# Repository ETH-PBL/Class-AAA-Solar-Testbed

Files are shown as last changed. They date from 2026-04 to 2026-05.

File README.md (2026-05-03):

<p align="center">
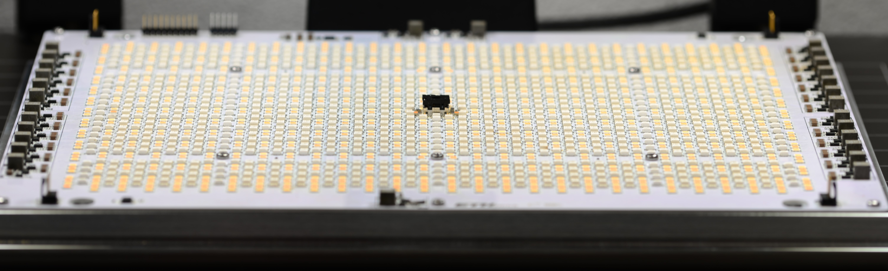
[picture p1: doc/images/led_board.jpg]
led board
  
</p>

# Open Source AAA-Grade Solar Testbed
This repository contains the hardware design files for the AAA-grade solar testbed.
It can accurately reproduce both indoor and outdoor lighting conditions, from ultra-low, narrow-band artificial light to full-spectrum sunlight. This enables a stable and repeatable evaluation environment with spectrally configurable illumination, making it ideal for evaluating ultra-low-power energy harvesting systems.

An in-depth analysis of the hardware can be found here: [arXiv.2604.24950 (preprint)](https://arxiv.org/abs/2604.24950)

> <div align="justify"> Energy harvesting promises maintenance-free operation of wireless sensor nodes but introduces strong dependencies on stochastic and deployment-specific environmental conditions. In particular, solar-powered systems are highly sensitive to variations in irradiance and spectral composition, which complicates system-level design, parameter tuning, and reliable verification. This work presents a solar testbed in which active control via Hardware-in-the-Loop (HIL) enables stable and repeatable illumination conditions for evaluating ultra-low-power energy harvesting systems. The proposed LED-based solar testbed provides spectrally configurable illumination over a wide dynamic range, from 5.7 mW/m2 to 908 kW/m2. It achieves Class AAA performance according to IEC 60904-9, with a spectral match below 1.3% and a spatial non-uniformity below 1.28% over a 16.5 cm x 16.5 cm test area. The long-term irradiance instability remains below 0.6%. Closed-loop control using integrated illuminance and spectral sensors ensures high temporal stability, while a temperature-controlled DUT stage supports long-term experiments. Experimental results demonstrate high repeatability and suitability for systematic laboratory characterization of solar energy harvesting systems.</div>

## Key Features
- **Class AAA Solar Simulator** compliant with [IEC 60904-9](https://webstore.iec.ch/publication/28973)
- **Spectrally tunable LED light source** composed of eight different LED types allows for emulation of natural and artificial light sources
- **Wide irradiance range** from **5.7 mW/m² to 908 W/m² (~1 lx to 110 klx)**
- **Large uniform illumination area** of 16.5 cm × 16.5 cm
- **Temperature-controlled platform** to keep the device under test (DUT) at a constant temperature

## Ussage
The solar testbed is designed to operate as part of a laboratory measurement setup in which a host computer, the testbed itself, and external measurement instruments interact closely. A computer connects to the testbed via USB and acts as the central orchestration unit. It configures and controls the illumination conditions, such as intensity and spectral composition, and coordinates the timing and execution of experiments.

Within this setup, the solar testbed provides a controlled and reproducible illumination environment but does not perform electrical measurements itself. The light board generates the desired illumination, while the internal control board distributes commands and manages the subsystems. The device under test (solar cell), is mounted on the carrier board, which ensures precise positioning and reproducible alignment within the illumination field.

Electrical access to the DUT is provided via two banana jack connectors. This allows the DUT to be interfaced directly with external measurement equipment, such as source measurement units, oscilloscopes, or data acquisition systems. Alternatively, an energy harvesting circuit can be connected between the solar cell and the measurement equipment, enabling system-level characterization under controlled lighting conditions.

The figure below show illustrates its functionality in a possible measurement setup.

<p align="center">
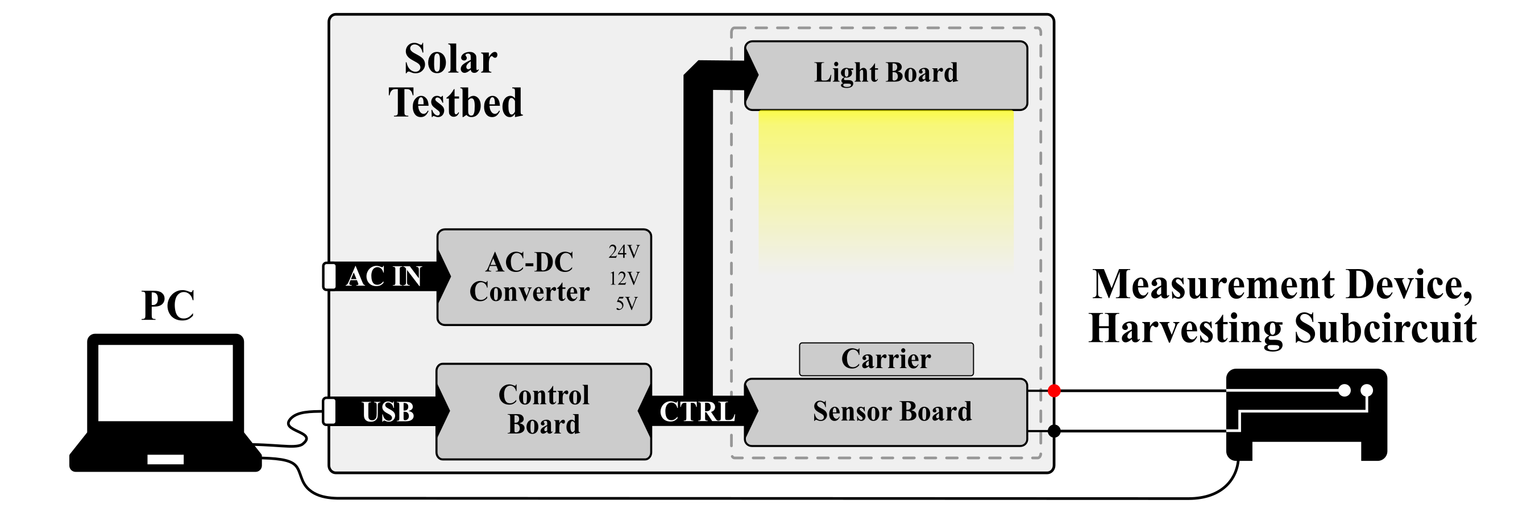
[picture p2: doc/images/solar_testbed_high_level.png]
solar tesbed high-level
  
</p>

# System Overview
The solar testbed is composed of both custom-designed and commercially available electronic and mechanical components. Its mechanical structure is based on custom heat sinks combined with standard 3030 aluminum profiles, enabling precise alignment and integration of all subsystems. While power stages and AC-to-DC converters are off-the-shelf components, the light source, sensing system, and control electronics are fully custom-designed.

The figure below provides a high-level overview of the main components.

<p align="center">
  led board
</p>

## Electrical
The testbed consists of four main subsystems implemented on separate PCBs:
- **Light Board:** A custom illumination board integrates 2964 LEDs of eight different types, mounted on a dedicated heat sink, enabling precise control of spectrum and intensity. It combines broadband visible LEDs, RGB LEDs for fine tuning, and infrared LEDs to emulate natural lighting conditions. The LEDs are driven by constant-current drivers with 16-bit dimming resolution, while integrated fan controllers ensure active cooling.

- **Sensor Board:** The sensor board monitors spectral distribution, illuminance, and temperature. It integrates an 18-channel spectrometer, two complementary ambient light sensors covering a wide illuminance range, and Peltier elements for temperature stabilization. Thermal control supports both heating and cooling, with additional fan-assisted stabilization.

- **Carrier Board:** The carrier board enables precise positioning and easy exchange of the device under test (DUT). It connects via an M.2 interface and provides external access through terminals. Integrated temperature sensing and controlled mounting ensure reproducible experimental conditions.

- **Control Board:** The control board coordinates all subsystems using an STM32 Cortex-M4 microcontroller. It manages illumination, temperature control, and overall system operation, and provides a USB Type-C interface for external communication. It further allows the addition of a single board comupter such as a Raspberry Pi to take control over high level control of the measurement  

All design files for the **custom designed PCBs** can be found [here](./hw/ecad/).  
Apart from the PCBs described above, the list of **commercial electrical components** used can be found [here](./hw/ecad/commercial_electrical_components.csv).

## Mechanical
The mechanical structur of the solar testbed consists of custom and commercial mechanical components.
Its mechanical structure is based on custom heat sinks combined with standard 3030 aluminum profiles.

- **Custom Parts:** 3D models and manufacturing drawings for the custom mechanical parts can be found [here](./hw/mcad/).

- **Commercial parts:** A list of commercially available mechanical components can be found here.

## Repository Structure
The repository has the following folders:  
- `doc` contains project documentation
- `hw` cntains all files of the solar testbed where in:
  - `ecad` all source files for the electronics (pcb design files, list of commerical components) are locaded
  - `mcad` all soruce files for mechanical componets (metal and plastic) including their 3d models and fabrication information are located

**Inportant:** This repository currently includes hardware only. Firmware, control software, and calibration tooling are not yet released. 

## Citation
If you use the solar testbed in an academic or industrial context, please cite the following publication:

```bibtex
@misc{schulthess_stb_2026,
    title           = {A Class AAA Solar Testbed for Reproducible Long-Term Characterization of Energy-Harvesting Systems}, 
    author          = {Lukas Schulthess and Andreas R\"atz and Michele Magno and Philipp Mayer},
    year            = {2026},
    eprint          = {2604.24950},
    archivePrefix   = {arXiv},
    doi             = {10.48550/arXiv.2604.24950},
    url             = {https://arxiv.org/abs/2604.24950}, 
}
```

## Contribution
The Solar Testbed has been designed at the [D-ITET Center-for Project-Based Learning](https://pbl.ee.ethz.ch/) and the [Integrated Systems Laboratory (IIS)](https://iis.ee.ethz.ch/) at ETH Zurch by:
 
[Lukas Schulthess](https://scholar.google.com/citations?user=nVuY91QAAAAJ&hl=en&oi=ao)  
[Philipp Mayer](https://scholar.google.com/citations?hl=en&user=1sCHClkAAAAJ)  
[Andreas Rätz](https://www.linkedin.com/in/andreas-r%C3%A4tz-2a439622b/)  

# License
All licenses used in this repository are licated in the `LICENSES` folder. 
Unless specified otherwise in the respective file headers, all code checked into this repository is made available under a permissive license.

- Hardware located under `hardware/` are lincense under the [Solderpad Hardware License v0.51](https://solderpad.org/licenses/SHL-0.51/) license.
- Markdown, JSON, text files, pictures, and PDFs are licensed under the [Creative Commons Attribution 4.0 International license](https://creativecommons.org/licenses/by/4.0/deed.en) (CC BY 4.0).

# Changelog
A detailed changelog is available in the [CHANGELOG.md](CHANGELOG.md) file, documenting major updates and design revisions.

## Disclaimer & Limitation of Liability
This project is a **research prototype** and is **not a commercial product**.  
It is provided for research, educational, and experimental purposes only. It is not certified for safety-critical or commercial use.

The system involves:
- high-intensity light sources  
- electrical power systems  
- thermal components (e.g., heating/cooling elements)  

Improper use, failures in self-assembly, or modification may result in:
ersonal injury  
- damage to equipment  
- unsafe operating conditions  

Users are solely responsible for ensuring safe design, assembly, and operation.

In no event and under no legal theory, whether in tort (including negligence), contract, or otherwise, unless required by applicable law (such as deliberate and grossly negligent acts) or agreed to in writing, shall any Contributor be liable to You for damages, including any direct, indirect, special, incidental, or consequential damages of any character arising as a result of this License or out of the use or inability to use the Work, including but not limited to:

- loss of goodwill  
- work stoppage  
- computer failure or malfunction  
- equipment damage  
- personal injury  
- or any other commercial or non-commercial damages or losses  

even if such contributor has been advised of the possibility of such damages.

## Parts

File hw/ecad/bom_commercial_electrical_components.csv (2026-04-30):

Component | Part Number / Model | Quantity
DC/DC Converter (54 W, 5 V out) | MEAN WELL DDR-60G-5 | 1
DC/DC Converter (60 W, 12 V out) | MEAN WELL DDR-60G-12 | 1
Power Supply Rail Mount 480W | Weidmuller 1469510000 | 1
Circuit Breaker | Weidmuller 2822220000 | 1
Peltier Module | Same Sky CP603315H | 4
Heat Sink Fan | NF-A14 PWM | 6
Door Sensor | Bernstein MAK-5236-BCD-6 | 1
Door Sensor Magnet | Bernstein TK-52-CD | 1
AC Power Entry Module | TE Connectivity 10CE1 M0 | 1
RGB Push Button | Metzler P19-TF-RGB | 1
HDMI Panel Mount | Adafruit 4129 | 1
Ethernet Panel Mount (RJ-45) | Adafruit 4130 | 1
USB-C Panel Mount | Adafruit 4261 | 1
Banana Jack 4mm (Red) | Cal Test CT4397-02-2 | 1
Banana Jack 4mm (Black) | Cal Test CT4397-02-0 | 1

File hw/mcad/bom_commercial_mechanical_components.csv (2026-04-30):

Name | Order Number | Supplier | Quantity
30x30 Aluminum Profile, B-Type Slot 8 (350 mm) | 30x30 B-Typ Nut 8 | Motedis | 10
30x30 Aluminum Profile, B-Type Slot 8 (485 mm) | 30x30 B-Typ Nut 8 | Motedis | 4
30x30 Aluminum Profile, B-Type Slot 8 (400 mm) | 30x30 B-Typ Nut 8 | Motedis | 2
Cube Connector 30, B-Type Slot 8 (2D) with cap | 65 | Motedis | 4
Cube Connector 30, B-Type Slot 8 (3D) with cap | 65 | Motedis | 4
Angle Bracket 30, B-Type Slot 8 | S8BBR30 | Motedis | 8
Cover and Edge Profile, Black, B-Type Slot 8 | 8PSIL08BR | Motedis | 10
Handle PA6 | 9343 | Motedis | 1
Hammer Nut, B-Type Slot 8 (M4) | S8BHASNM4 | Motedis | 4
Hammer Nut, B-Type Slot 8 (M5) | S8BHASNM5 | Motedis | 20
Hammer Nut, B-Type Slot 8 (M6) | S8BHASNM6 | Motedis | 20
Countersunk screw DIN 7991 M8x25 | 1120 | Motedis | 20
Countersunk screw DIN 7991 M4x12 | 1120 | Motedis | 20
Screw DIN 912 M6x12 | 1121 | Motedis
Wheel 75mm | 06.07.05 | Motedis | 4
Zinc Die-Cast Hinge | GN 127-ZD-52-40-B-SW | Hanser | 3
Draw latches | GN 936-72-SCL-SW | Hanser | 1
Metal Housing for power subsystem | ALN314016B | Fibox | 1

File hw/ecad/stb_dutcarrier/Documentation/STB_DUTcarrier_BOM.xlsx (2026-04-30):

Quantity | Designator | Comment | Value | Tolerance | Power | Footprint | Manufacturer | Manufacturer Part Number
1 | C1 | 100nF | 100nF |  |  | CAPC1050X55X23LL05T13 | Samsung Electro-Mechanics | CL05B104KO5NNNC
1 | R2 | 100k | 100 kOhm | 1% |  | RESC1005X40X25LL05T10 | Yageo / Phycomp | RC0402FR-07100KL
1 | U1 | TMP116NAIDRVR |  |  |  | FP-DRV0006B-MFG | Texas Instruments | TMP116NAIDRVR

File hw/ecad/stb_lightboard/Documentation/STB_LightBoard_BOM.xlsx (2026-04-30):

Quantity | Designator | Comment | Value | Tolerance | Power | Footprint | Manufacturer | Manufacturer Part Number
1 | J1 | 1050281001 |  |  |  | FP-1050281001-MFG | Molex | 1050281001
1 | L2 | DFE201612E-2R2M=P2 | 2.2uH | ±20% |  | INDC2016X10L | Murata Electronics | DFE201612E-2R2M=P2
1 | R2 | 0R |  |  |  | RESC1005X40X25LL05T10 | Yageo / Phycomp | RC0402JR-070RL
1 | R93 | 100k | 100 kOhm | 1% |  | RESC1005X40X25LL05T10 | Yageo / Phycomp | RC0402FR-07100KL
1 | U2 | N24S64BC4DYT3G |  |  |  | 4-WLCSP (0.77x0.77) | ON Semiconductor | N24S64BC4DYT3G
1 | U7 | LM3674MF-1.2/NOPB |  |  |  | DBV0005A_N | Texas Instruments | LM3674MF-1.2/NOPB
1 | U8 | TCA9800DGKT |  |  |  | DGK0008A_L | Texas Instruments | TCA9800DGKT
1 | U9 | SN74AXC4T774PWR |  |  |  | FP-PW0016A-IPC_B | Texas Instruments | SN74AXC4T774PWR
1 | X3 | 61002021121 |  |  |  | 61002021121 | Wurth Elektronik | 61002021121
1 | X4 | TSM-105-01-T-DV-TR |  |  |  | SMTC-TSM-105-01-T-DV_V | Samtec | TSM-105-01-T-DV-TR
1 | Y1 | ASEMB-25.000MHZ-LC-T |  |  |  | FP-ASEMB-MFG | Abracon | ASEMB-25.000MHZ-LC-T
2 | U1_TC1, U1_TC2 | MAX6615AEE+T |  |  |  | MAXM-E16+1_M | Maxim | MAX6615AEE+T
2 | U5, U6 | ADP124ARHZ-2.8-R7 |  |  |  | ADI-RH-8-1_N | Analog Devices | ADP124ARHZ-2.8-R7
3 | Q2, Q3, Q4 | 2N7002-7-F |  |  |  | FP-SOT23-MFG | Diodes | 2N7002-7-F
3 | R4, R12, R27 | 182k | 182 kOhm | 1% |  | RESC1005X40X25LL05T05 | Vishay Dale | CRCW0402182KFKED
3 | R15, R25, R63 | 280k | 280 kOhm | 1% |  | RESC1005X40X25LL05T05 | Basic Passives | ERJ-2RKF2803X
4 | C2_TC1, C2_TC2, C3_TC1, C3_TC2 | 100pF | 100pF |  |  | CAPC1005X56X25LL10T15 | AVX Interconnect / Elco | 04023A101KAT2A
4 | R13, R34, R74, R85 | 523k | 523 kOhm | 1% |  | RESC1005X40X25LL05T05 | Panasonic | ERJ-2RKF5233X
4 | R14, R33, R64, R89 | 392k | 392 kOhm | 1% |  | RESC1005X40X25LL05T05 | Panasonic | ERJ-2RKF3923X
4 | R32, R36, R69, R76 | 887k | 887 kOhm | 1% |  | RESC1005X40X25LL05T10 | Yageo / Phycomp | RC0402FR-07887KL
4 | R35, R37, R40, R75 | 681k | 681 kOhm | 1% |  | RESC1005X40X25LL05T05 | Panasonic | ERJ-2RKF6813X
4 | R50_TC1, R50_TC2, R52_TC1, R52_TC2 | 1k6 | 1.6 kOhm | 1% |  | RESC1005X40X25LL05T10 | Yageo / Phycomp | RC0402FR-071K6L
4 | R51_TC1, R51_TC2, R53_TC1, R53_TC2 | NCP15XH103F03RC | 10 kOhm | 1% |  | FP-NCP15-NCU15-0_05-IPC_C | Murata | NCP15XH103F03RC
4 | X1_TC1, X1_TC2, X2_TC1, X2_TC2 | 3-647168-4 |  |  |  | 3-647168-4 | TE Connectivity | 3-647166-4
15 | R5, R9, R10, R11, R20, R26, R43, R67, R68, R81, R82, R83, R84, R88, R92 | 102k | 102 kOhm | 1% |  | RESC1005X40X25LL05T05 | Panasonic | ERJ-2RKF1023X
18 | R1, R3, R6, R7, R8, R16, R21, R23, R24, R42, R65, R66, R77, R78, R79, R80, R87, R91 | 976k | 976 kOhm | 1% |  | RESC1005X40X25LL05T05 | Panasonic | ERJ-2RKF9763X
19 | R17, R18, R19, R22, R28, R29, R30, R31, R38, R39, R41, R61, R62, R70, R71, R72, R73, R86, R90 | 1M | 1 MOhm | 1% |  | RESC1005X40X25LL05T05 | Basic Passives | ERJ-2RKF1004X
28 | C7_D0, C7_D1, C7_D2, C7_D3, C7_D4, C7_D5, C7_D6, C7_D7, C7_D8, C7_D9, C7_D10, C7_D11, C7_D12, C7_D13, C7_D14, C7_D15, C7_D16, C7_D17, C7_D18, C7_D19, C7_D20, C7_D21, C7_D22, C7_D23, C7_D24, C7_D25, C7_D26, C7_D27 | 30pF | 30 pF |  |  | CAPC1005X56X25LL10T15 | AVX Interconnect / Elco | 04025A300JAT2A
28 | C12_D0, C12_D1, C12_D2, C12_D3, C12_D4, C12_D5, C12_D6, C12_D7, C12_D8, C12_D9, C12_D10, C12_D11, C12_D12, C12_D13, C12_D14, C12_D15, C12_D16, C12_D17, C12_D18, C12_D19, C12_D20, C12_D21, C12_D22, C12_D23, C12_D24, C12_D25, C12_D26, C12_D27 | 1nF | 1 nF | 10% |  | CAPC1005X55X25LL5T10 | Murata | GRM155R71H102KA01D
28 | C16_D0, C16_D1, C16_D2, C16_D3, C16_D4, C16_D5, C16_D6, C16_D7, C16_D8, C16_D9, C16_D10, C16_D11, C16_D12, C16_D13, C16_D14, C16_D15, C16_D16, C16_D17, C16_D18, C16_D19, C16_D20, C16_D21, C16_D22, C16_D23, C16_D24, C16_D25, C16_D26, C16_D27 | 390pF | 390pF |  |  | CAPC1005X56X25LL10T15 | AVX Interconnect / Elco | 04025C391JAT2A
28 | C17_D0, C17_D1, C17_D2, C17_D3, C17_D4, C17_D5, C17_D6, C17_D7, C17_D8, C17_D9, C17_D10, C17_D11, C17_D12, C17_D13, C17_D14, C17_D15, C17_D16, C17_D17, C17_D18, C17_D19, C17_D20, C17_D21, C17_D22, C17_D23, C17_D24, C17_D25, C17_D26, C17_D27 | 3.3nF | 3.3nF |  |  | CAPC1005X56X25LL10T15 | AVX Interconnect / Elco | 04023C332KAT2A
28 | D1_D0, D1_D1, D1_D2, D1_D3, D1_D4, D1_D5, D1_D6, D1_D7, D1_D8, D1_D9, D1_D10, D1_D11, D1_D12, D1_D13, D1_D14, D1_D15, D1_D16, D1_D17, D1_D18, D1_D19, D1_D20, D1_D21, D1_D22, D1_D23, D1_D24, D1_D25, D1_D26, D1_D27 | PMEG6030EVPX |  |  |  | SOD-128 | Nexperia | PMEG6030EVPX
28 | L1_D0, L1_D1, L1_D2, L1_D3, L1_D4, L1_D5, L1_D6, L1_D7, L1_D8, L1_D9, L1_D10, L1_D11, L1_D12, L1_D13, L1_D14, L1_D15, L1_D16, L1_D17, L1_D18, L1_D19, L1_D20, L1_D21, L1_D22, L1_D23, L1_D24, L1_D25, L1_D26, L1_D27 | 15uH | 15uH | 20% |  | FP-XAL6060-MFG | Coilcraft | XAL6060-153MEC
28 | Q1_D0, Q1_D1, Q1_D2, Q1_D3, Q1_D4, Q1_D5, Q1_D6, Q1_D7, Q1_D8, Q1_D9, Q1_D10, Q1_D11, Q1_D12, Q1_D13, Q1_D14, Q1_D15, Q1_D16, Q1_D17, Q1_D18, Q1_D19, Q1_D20, Q1_D21, Q1_D22, Q1_D23, Q1_D24, Q1_D25, Q1_D26, Q1_D27 | FDMC4435BZ |  |  |  | FP-511DQ-MFG | ON Semiconductor | FDMC4435BZ
28 | R54_D0, R54_D1, R54_D2, R54_D3, R54_D4, R54_D5, R54_D6, R54_D7, R54_D8, R54_D9, R54_D10, R54_D11, R54_D12, R54_D13, R54_D14, R54_D15, R54_D16, R54_D17, R54_D18, R54_D19, R54_D20, R54_D21, R54_D22, R54_D23, R54_D24, R54_D25, R54_D26, R54_D27 | 316k | 316 kOhm | 1% |  | RESC1005X40X25LL05T05 | Panasonic | ERJ-2RKF3163X
28 | R59_D0, R59_D1, R59_D2, R59_D3, R59_D4, R59_D5, R59_D6, R59_D7, R59_D8, R59_D9, R59_D10, R59_D11, R59_D12, R59_D13, R59_D14, R59_D15, R59_D16, R59_D17, R59_D18, R59_D19, R59_D20, R59_D21, R59_D22, R59_D23, R59_D24, R59_D25, R59_D26, R59_D27 | 8.2k | 8.2 kOhm | 1% |  | RESC1005X40X25LL05T05 | Vishay Dale | CRCW04028K20FKED
28 | R60_D0, R60_D1, R60_D2, R60_D3, R60_D4, R60_D5, R60_D6, R60_D7, R60_D8, R60_D9, R60_D10, R60_D11, R60_D12, R60_D13, R60_D14, R60_D15, R60_D16, R60_D17, R60_D18, R60_D19, R60_D20, R60_D21, R60_D22, R60_D23, R60_D24, R60_D25, R60_D26, R60_D27 | 3k | 3 kOhm | 1% |  | RESC1005X40X25LL05T10 | Yageo / Phycomp | RC0402FR-073KL
28 | U3_D0, U3_D1, U3_D2, U3_D3, U3_D4, U3_D5, U3_D6, U3_D7, U3_D8, U3_D9, U3_D10, U3_D11, U3_D12, U3_D13, U3_D14, U3_D15, U3_D16, U3_D17, U3_D18, U3_D19, U3_D20, U3_D21, U3_D22, U3_D23, U3_D24, U3_D25, U3_D26, U3_D27 | ISL78171ARZ-T7A |  |  |  | LT-UDC-20_N | Renesas | ISL78171ARZ-T7A
28 | U4_D0, U4_D1, U4_D2, U4_D3, U4_D4, U4_D5, U4_D6, U4_D7, U4_D8, U4_D9, U4_D10, U4_D11, U4_D12, U4_D13, U4_D14, U4_D15, U4_D16, U4_D17, U4_D18, U4_D19, U4_D20, U4_D21, U4_D22, U4_D23, U4_D24, U4_D25, U4_D26, U4_D27 | LTC4316IDD#TRPBF |  |  |  | DFN10(3x3)_N | Analog Devices / Linear Technology | LTC4316IDD#TRPBF
29 | C15_D0, C15_D1, C15_D2, C15_D3, C15_D4, C15_D5, C15_D6, C15_D7, C15_D8, C15_D9, C15_D10, C15_D11, C15_D12, C15_D13, C15_D14, C15_D15, C15_D16, C15_D17, C15_D18, C15_D19, C15_D20, C15_D21, C15_D22, C15_D23, C15_D24, C15_D25, C15_D26, C15_D27, C26 | 1uF | 1uF |  |  | CAPC1608X90X35LL15T15 | Kemet | C0603C105K4RACTU
31 | C1_TC1, C1_TC2, C4, C14_D0, C14_D1, C14_D2, C14_D3, C14_D4, C14_D5, C14_D6, C14_D7, C14_D8, C14_D9, C14_D10, C14_D11, C14_D12, C14_D13, C14_D14, C14_D15, C14_D16, C14_D17, C14_D18, C14_D19, C14_D20, C14_D21, C14_D22, C14_D23, C14_D24, C14_D25, C14_D26, C14_D27 | 100nF | 100nF |  |  | CAPC1050X55X23LL05T13 | Samsung Electro-Mechanics | CL05B104KO5NNNC
32 | C13_D0, C13_D1, C13_D2, C13_D3, C13_D4, C13_D5, C13_D6, C13_D7, C13_D8, C13_D9, C13_D10, C13_D11, C13_D12, C13_D13, C13_D14, C13_D15, C13_D16, C13_D17, C13_D18, C13_D19, C13_D20, C13_D21, C13_D22, C13_D23, C13_D24, C13_D25, C13_D26, C13_D27, C24, C25, C29, C30 | 100nF/50V | 100nF | 5% |  | FP-CL10-0_1-MFG | Samsung Electro-Mechanics America, Inc | CL10B104JB8NNNC
63 | R48_TC1, R48_TC2, R49_TC1, R49_TC2, R55_D0, R55_D1, R55_D2, R55_D3, R55_D4, R55_D5, R55_D6, R55_D7, R55_D8, R55_D9, R55_D10, R55_D11, R55_D12, R55_D13, R55_D14, R55_D15, R55_D16, R55_D17, R55_D18, R55_D19, R55_D20, R55_D21, R55_D22, R55_D23, R55_D24, R55_D25, R55_D26, R55_D27, R58_D0, R58_D1, R58_D2, R58_D3, R58_D4, R58_D5, R58_D6, R58_D7, R58_D8, R58_D9, R58_D10, R58_D11, R58_D12, R58_D13, R58_D14, R58_D15, R58_D16, R58_D17, R58_D18, R58_D19, R58_D20, R58_D21, R58_D22, R58_D23, R58_D24, R58_D25, R58_D26, R58_D27, R94, R95, R96 | 10k | 10 KOhm | 1% |  | RESC1005X40X25LL05T05 | Panasonic | ERJ-2RKF1002X
64 | R44_TC1, R44_TC2, R45_TC1, R45_TC2, R46_TC1, R46_TC2, R47_TC1, R47_TC2, R56_D0, R56_D1, R56_D2, R56_D3, R56_D4, R56_D5, R56_D6, R56_D7, R56_D8, R56_D9, R56_D10, R56_D11, R56_D12, R56_D13, R56_D14, R56_D15, R56_D16, R56_D17, R56_D18, R56_D19, R56_D20, R56_D21, R56_D22, R56_D23, R56_D24, R56_D25, R56_D26, R56_D27, R57_D0, R57_D1, R57_D2, R57_D3, R57_D4, R57_D5, R57_D6, R57_D7, R57_D8, R57_D9, R57_D10, R57_D11, R57_D12, R57_D13, R57_D14, R57_D15, R57_D16, R57_D17, R57_D18, R57_D19, R57_D20, R57_D21, R57_D22, R57_D23, R57_D24, R57_D25, R57_D26, R57_D27 | 4k7 | 4.7 kOhm | 1% |  | RESC1005X40X25LL05T10 | Yageo / Phycomp | RC0402FR-074K7L
72 | LED78_g_10, LED78_g_11, LED78_g_12, LED78_g_13, LED78_g_14, LED78_g_15, LED79_g_10, LED79_g_11, LED79_g_12, LED79_g_13, LED79_g_14, LED79_g_15, LED80_g_10, LED80_g_11, LED80_g_12, LED80_g_13, LED80_g_14, LED80_g_15, LED81_g_10, LED81_g_11, LED81_g_12, LED81_g_13, LED81_g_14, LED81_g_15, LED82_g_10, LED82_g_11, LED82_g_12, LED82_g_13, LED82_g_14, LED82_g_15, LED83_g_10, LED83_g_11, LED83_g_12, LED83_g_13, LED83_g_14, LED83_g_15, LED84_g_10, LED84_g_11, LED84_g_12, LED84_g_13, LED84_g_14, LED84_g_15, LED85_g_10, LED85_g_11, LED85_g_12, LED85_g_13, LED85_g_14, LED85_g_15, LED86_g_10, LED86_g_11, LED86_g_12, LED86_g_13, LED86_g_14, LED86_g_15, LED87_g_10, LED87_g_11, LED87_g_12, LED87_g_13, LED87_g_14, LED87_g_15, LED88_g_10, LED88_g_11, LED88_g_12, LED88_g_13, LED88_g_14, LED88_g_15, LED89_g_10, LED89_g_11, LED89_g_12, LED89_g_13, LED89_g_14, LED89_g_15 | NE2G757GT |  |  |  | NE2G757GT | Nichia | NE2G757GT
84 | LED135_b_10, LED135_b_11, LED135_b_12, LED135_b_13, LED135_b_14, LED135_b_15, LED136_b_10, LED136_b_11, LED136_b_12, LED136_b_13, LED136_b_14, LED136_b_15, LED137_b_10, LED137_b_11, LED137_b_12, LED137_b_13, LED137_b_14, LED137_b_15, LED138_b_10, LED138_b_11, LED138_b_12, LED138_b_13, LED138_b_14, LED138_b_15, LED139_b_10, LED139_b_11, LED139_b_12, LED139_b_13, LED139_b_14, LED139_b_15, LED140_b_10, LED140_b_11, LED140_b_12, LED140_b_13, LED140_b_14, LED140_b_15, LED141_b_10, LED141_b_11, LED141_b_12, LED141_b_13, LED141_b_14, LED141_b_15, LED142_b_10, LED142_b_11, LED142_b_12, LED142_b_13, LED142_b_14, LED142_b_15, LED143_b_10, LED143_b_11, LED143_b_12, LED143_b_13, LED143_b_14, LED143_b_15, LED144_b_10, LED144_b_11, LED144_b_12, LED144_b_13, LED144_b_14, LED144_b_15, LED145_b_10, LED145_b_11, LED145_b_12, LED145_b_13, LED145_b_14, LED145_b_15, LED146_b_10, LED146_b_11, LED146_b_12, LED146_b_13, LED146_b_14, LED146_b_15, LED147_b_10, LED147_b_11, LED147_b_12, LED147_b_13, LED147_b_14, LED147_b_15, LED148_b_10, LED148_b_11, LED148_b_12, LED148_b_13, LED148_b_14, LED148_b_15 | NE2B757GT |  |  |  | NE2B757GT | Nichia | NE2B757GT
120 | LED1_r_10, LED1_r_11, LED1_r_12, LED1_r_13, LED1_r_14, LED1_r_15, LED2_r_10, LED2_r_11, LED2_r_12, LED2_r_13, LED2_r_14, LED2_r_15, LED3_r_10, LED3_r_11, LED3_r_12, LED3_r_13, LED3_r_14, LED3_r_15, LED4_r_10, LED4_r_11, LED4_r_12, LED4_r_13, LED4_r_14, LED4_r_15, LED5_r_10, LED5_r_11, LED5_r_12, LED5_r_13, LED5_r_14, LED5_r_15, LED6_r_10, LED6_r_11, LED6_r_12, LED6_r_13, LED6_r_14, LED6_r_15, LED7_r_10, LED7_r_11, LED7_r_12, LED7_r_13, LED7_r_14, LED7_r_15, LED8_r_10, LED8_r_11, LED8_r_12, LED8_r_13, LED8_r_14, LED8_r_15, LED9_r_10, LED9_r_11, LED9_r_12, LED9_r_13, LED9_r_14, LED9_r_15, LED10_r_10, LED10_r_11, LED10_r_12, LED10_r_13, LED10_r_14, LED10_r_15, LED11_r_10, LED11_r_11, LED11_r_12, LED11_r_13, LED11_r_14, LED11_r_15, LED12_r_10, LED12_r_11, LED12_r_12, LED12_r_13, LED12_r_14, LED12_r_15, LED13_r_10, LED13_r_11, LED13_r_12, LED13_r_13, LED13_r_14, LED13_r_15, LED14_r_10, LED14_r_11, LED14_r_12, LED14_r_13, LED14_r_14, LED14_r_15, LED42_r_10, LED42_r_11, LED42_r_12, LED42_r_13, LED42_r_14, LED42_r_15, LED130_r_10, LED130_r_11, LED130_r_12, LED130_r_13, LED130_r_14, LED130_r_15, LED131_r_10, LED131_r_11, LED131_r_12, LED131_r_13, LED131_r_14, LED131_r_15, LED132_r_10, LED132_r_11, LED132_r_12, LED132_r_13, LED132_r_14, LED132_r_15, LED133_r_10, LED133_r_11, LED133_r_12, LED133_r_13, LED133_r_14, LED133_r_15, LED134_r_10, LED134_r_11, LED134_r_12, LED134_r_13, LED134_r_14, LED134_r_15 | NE2R757GT-P6 |  |  |  | NE2R757GT-P6 | Nichia | NE2R757GT-P6
177 | C5_D0, C5_D1, C5_D2, C5_D3, C5_D4, C5_D5, C5_D6, C5_D7, C5_D8, C5_D9, C5_D10, C5_D11, C5_D12, C5_D13, C5_D14, C5_D15, C5_D16, C5_D17, C5_D18, C5_D19, C5_D20, C5_D21, C5_D22, C5_D23, C5_D24, C5_D25, C5_D26, C5_D27, C6_D0, C6_D1, C6_D2, C6_D3, C6_D4, C6_D5, C6_D6, C6_D7, C6_D8, C6_D9, C6_D10, C6_D11, C6_D12, C6_D13, C6_D14, C6_D15, C6_D16, C6_D17, C6_D18, C6_D19, C6_D20, C6_D21, C6_D22, C6_D23, C6_D24, C6_D25, C6_D26, C6_D27, C8_D0, C8_D1, C8_D2, C8_D3, C8_D4, C8_D5, C8_D6, C8_D7, C8_D8, C8_D9, C8_D10, C8_D11, C8_D12, C8_D13, C8_D14, C8_D15, C8_D16, C8_D17, C8_D18, C8_D19, C8_D20, C8_D21, C8_D22, C8_D23, C8_D24, C8_D25, C8_D26, C8_D27, C9_D0, C9_D1, C9_D2, C9_D3, C9_D4, C9_D5, C9_D6, C9_D7, C9_D8, C9_D9, C9_D10, C9_D11, C9_D12, C9_D13, C9_D14, C9_D15, C9_D16, C9_D17, C9_D18, C9_D19, C9_D20, C9_D21, C9_D22, C9_D23, C9_D24, C9_D25, C9_D26, C9_D27, C10_D0, C10_D1, C10_D2, C10_D3, C10_D4, C10_D5, C10_D6, C10_D7, C10_D8, C10_D9, C10_D10, C10_D11, C10_D12, C10_D13, C10_D14, C10_D15, C10_D16, C10_D17, C10_D18, C10_D19, C10_D20, C10_D21, C10_D22, C10_D23, C10_D24, C10_D25, C10_D26, C10_D27, C11_D0, C11_D1, C11_D2, C11_D3, C11_D4, C11_D5, C11_D6, C11_D7, C11_D8, C11_D9, C11_D10, C11_D11, C11_D12, C11_D13, C11_D14, C11_D15, C11_D16, C11_D17, C11_D18, C11_D19, C11_D20, C11_D21, C11_D22, C11_D23, C11_D24, C11_D25, C11_D26, C11_D27, C18, C19, C20, C21, C22, C23, C27, C31, C34 | 10uF/50V | 10uF | 10% |  | FP-CL31B106KBHNNNE-MFG | Samsung | CL31B106KBHNNNE
312 | LED104_IR850_10, LED104_IR850_11, LED104_IR850_12, LED104_IR850_13, LED104_IR850_14, LED104_IR850_15, LED104_IR850_20, LED104_IR850_21, LED104_IR850_22, LED104_IR850_23, LED104_IR850_24, LED104_IR850_25, LED105_IR850_10, LED105_IR850_11, LED105_IR850_12, LED105_IR850_13, LED105_IR850_14, LED105_IR850_15, LED105_IR850_20, LED105_IR850_21, LED105_IR850_22, LED105_IR850_23, LED105_IR850_24, LED105_IR850_25, LED106_IR850_10, LED106_IR850_11, LED106_IR850_12, LED106_IR850_13, LED106_IR850_14, LED106_IR850_15, LED106_IR850_20, LED106_IR850_21, LED106_IR850_22, LED106_IR850_23, LED106_IR850_24, LED106_IR850_25, LED107_IR850_10, LED107_IR850_11, LED107_IR850_12, LED107_IR850_13, LED107_IR850_14, LED107_IR850_15, LED107_IR850_20, LED107_IR850_21, LED107_IR850_22, LED107_IR850_23, LED107_IR850_24, LED107_IR850_25, LED108_IR850_10, LED108_IR850_11, LED108_IR850_12, LED108_IR850_13, LED108_IR850_14, LED108_IR850_15, LED108_IR850_20, LED108_IR850_21, LED108_IR850_22, LED108_IR850_23, LED108_IR850_24, LED108_IR850_25, LED109_IR850_10, LED109_IR850_11, LED109_IR850_12, LED109_IR850_13, LED109_IR850_14, LED109_IR850_15, LED109_IR850_20, LED109_IR850_21, LED109_IR850_22, LED109_IR850_23, LED109_IR850_24, LED109_IR850_25, LED110_IR850_10, LED110_IR850_11, LED110_IR850_12, LED110_IR850_13, LED110_IR850_14, LED110_IR850_15, LED110_IR850_20, LED110_IR850_21, LED110_IR850_22, LED110_IR850_23, LED110_IR850_24, LED110_IR850_25, LED111_IR850_10, LED111_IR850_11, LED111_IR850_12, LED111_IR850_13, LE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 | AREM-80C0-LM000 |  |  |  | AREM-80C0-LM000 | Broadcom | AREM-80C0-LM000
420 | LED90_W3_10, LED90_W3_11, LED90_W3_12, LED90_W3_13, LED90_W3_14, LED90_W3_15, LED90_W3_20, LED90_W3_21, LED90_W3_22, LED90_W3_23, LED90_W3_24, LED90_W3_25, LED90_W3_30, LED90_W3_31, LED90_W3_32, LED90_W3_33, LED90_W3_34, LED90_W3_35, LED90_W3_40, LED90_W3_41, LED90_W3_42, LED90_W3_43, LED90_W3_44, LED90_W3_45, LED90_W3_50, LED90_W3_51, LED90_W3_52, LED90_W3_53, LED90_W3_54, LED90_W3_55, LED91_W3_10, LED91_W3_11, LED91_W3_12, LED91_W3_13, LED91_W3_14, LED91_W3_15, LED91_W3_20, LED91_W3_21, LED91_W3_22, LED91_W3_23, LED91_W3_24, LED91_W3_25, LED91_W3_30, LED91_W3_31, LED91_W3_32, LED91_W3_33, LED91_W3_34, LED91_W3_35, LED91_W3_40, LED91_W3_41, LED91_W3_42, LED91_W3_43, LED91_W3_44, LED91_W3_45, LED91_W3_50, LED91_W3_51, LED91_W3_52, LED91_W3_53, LED91_W3_54, LED91_W3_55, LED92_W3_10, LED92_W3_11, LED92_W3_12, LED92_W3_13, LED92_W3_14, LED92_W3_15, LED92_W3_20, LED92_W3_21, LED92_W3_22, LED92_W3_23, LED92_W3_24, LED92_W3_25, LED92_W3_30, LED92_W3_31, LED92_W3_32, LED92_W3_33, LED92_W3_34, LED92_W3_35, LED92_W3_40, LED92_W3_41, LED92_W3_42, LED92_W3_43, LED92_W3_44, LED92_W3_45, LED92_W3_50, LED92_W3_51, LED92_W3_52, LED92_W3_53, LED92_W3_54, LED92_W3_55, LED93_W3_10, LED93_W3_11, LED93_W3_12, LED93_W3_13, LED93_W3_14, LED93_W3_15, LED93_W3_20, LED93_W3_21, LED93_W3_22, LED93_W3_23, LED93_W3_24, LED93_W3_25, LED93_W3_30, LED93_W3_31, LED93_W3_32, LED93_W3_33, LED93_W3_34, LED93_W3_35, LED93_W3_40, LED93_W3_41, LED93_W3_42, LED93_W3_43, LED93_W3_44, LED93_W3_45, LED93_W3_50, LED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 | NF2L757GT-F1 |  |  |  | NF2W757GT-F1 | Nichia | NF2L757GT-F1 Optisolis
528 | LED43_IR740_10, LED43_IR740_11, LED43_IR740_12, LED43_IR740_13, LED43_IR740_14, LED43_IR740_15, LED43_IR740_20, LED43_IR740_21, LED43_IR740_22, LED43_IR740_23, LED43_IR740_24, LED43_IR740_25, LED43_IR740_30, LED43_IR740_31, LED43_IR740_32, LED43_IR740_33, LED43_IR740_34, LED43_IR740_35, LED43_IR740_40, LED43_IR740_41, LED43_IR740_42, LED43_IR740_43, LED43_IR740_44, LED43_IR740_45, LED44_IR740_10, LED44_IR740_11, LED44_IR740_12, LED44_IR740_13, LED44_IR740_14, LED44_IR740_15, LED44_IR740_20, LED44_IR740_21, LED44_IR740_22, LED44_IR740_23, LED44_IR740_24, LED44_IR740_25, LED44_IR740_30, LED44_IR740_31, LED44_IR740_32, LED44_IR740_33, LED44_IR740_34, LED44_IR740_35, LED44_IR740_40, LED44_IR740_41, LED44_IR740_42, LED44_IR740_43, LED44_IR740_44, LED44_IR740_45, LED45_IR740_10, LED45_IR740_11, LED45_IR740_12, LED45_IR740_13, LED45_IR740_14, LED45_IR740_15, LED45_IR740_20, LED45_IR740_21, LED45_IR740_22, LED45_IR740_23, LED45_IR740_24, LED45_IR740_25, LED45_IR740_30, LED45_IR740_31, LED45_IR740_32, LED45_IR740_33, LED45_IR740_34, LED45_IR740_35, LED45_IR740_40, LED45_IR740_41, LED45_IR740_42, LED45_IR740_43, LED45_IR740_44, LED45_IR740_45, LED46_IR740_10, LED46_IR740_11, LED46_IR740_12, LED46_IR740_13, LED46_IR740_14, LED46_IR740_15, LED46_IR740_20, LED46_IR740_21, LED46_IR740_22, LED46_IR740_23, LED46_IR740_24, LED46_IR740_25, LED46_IR740_30, LED46_IR740_31, LED46_IR740_32, LED46_IR740_33, LED46_IR740_34, LED46_IR740_35, LED46_IR740_40, LED46_IR740_41, LED46_IR740_42, LED46_IR74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 | QBHP686-IR4D |  |  |  | QBHP686-IR4D | QT-Brightek | QBHP686-IR4D
648 | LED15_IR940_10, LED15_IR940_11, LED15_IR940_12, LED15_IR940_13, LED15_IR940_14, LED15_IR940_15, LED15_IR940_20, LED15_IR940_21, LED15_IR940_22, LED15_IR940_23, LED15_IR940_24, LED15_IR940_25, LED15_IR940_30, LED15_IR940_31, LED15_IR940_32, LED15_IR940_33, LED15_IR940_34, LED15_IR940_35, LED15_IR940_40, LED15_IR940_41, LED15_IR940_42, LED15_IR940_43, LED15_IR940_44, LED15_IR940_45, LED16_IR940_10, LED16_IR940_11, LED16_IR940_12, LED16_IR940_13, LED16_IR940_14, LED16_IR940_15, LED16_IR940_20, LED16_IR940_21, LED16_IR940_22, LED16_IR940_23, LED16_IR940_24, LED16_IR940_25, LED16_IR940_30, LED16_IR940_31, LED16_IR940_32, LED16_IR940_33, LED16_IR940_34, LED16_IR940_35, LED16_IR940_40, LED16_IR940_41, LED16_IR940_42, LED16_IR940_43, LED16_IR940_44, LED16_IR940_45, LED17_IR940_10, LED17_IR940_11, LED17_IR940_12, LED17_IR940_13, LED17_IR940_14, LED17_IR940_15, LED17_IR940_20, LED17_IR940_21, LED17_IR940_22, LED17_IR940_23, LED17_IR940_24, LED17_IR940_25, LED17_IR940_30, LED17_IR940_31, LED17_IR940_32, LED17_IR940_33, LED17_IR940_34, LED17_IR940_35, LED17_IR940_40, LED17_IR940_41, LED17_IR940_42, LED17_IR940_43, LED17_IR940_44, LED17_IR940_45, LED18_IR940_10, LED18_IR940_11, LED18_IR940_12, LED18_IR940_13, LED18_IR940_14, LED18_IR940_15, LED18_IR940_20, LED18_IR940_21, LED18_IR940_22, LED18_IR940_23, LED18_IR940_24, LED18_IR940_25, LED18_IR940_30, LED18_IR940_31, LED18_IR940_32, LED18_IR940_33, LED18_IR940_34, LED18_IR940_35, LED18_IR940_40, LED18_IR940_41, LED18_IR940_42, LED18_IR94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 | AREM-90C0-KL000 |  |  |  | AREM-80C0-LM000 | Broadcom | AREM-90C0-KL000
780 | LED65_W5_10, LED65_W5_11, LED65_W5_12, LED65_W5_13, LED65_W5_14, LED65_W5_15, LED65_W5_20, LED65_W5_21, LED65_W5_22, LED65_W5_23, LED65_W5_24, LED65_W5_25, LED65_W5_30, LED65_W5_31, LED65_W5_32, LED65_W5_33, LED65_W5_34, LED65_W5_35, LED65_W5_40, LED65_W5_41, LED65_W5_42, LED65_W5_43, LED65_W5_44, LED65_W5_45, LED65_W5_50, LED65_W5_51, LED65_W5_52, LED65_W5_53, LED65_W5_54, LED65_W5_55, LED65_W5_60, LED65_W5_61, LED65_W5_62, LED65_W5_63, LED65_W5_64, LED65_W5_65, LED65_W5_70, LED65_W5_71, LED65_W5_72, LED65_W5_73, LED65_W5_74, LED65_W5_75, LED65_W5_80, LED65_W5_81, LED65_W5_82, LED65_W5_83, LED65_W5_84, LED65_W5_85, LED65_W5_90, LED65_W5_91, LED65_W5_92, LED65_W5_93, LED65_W5_94, LED65_W5_95, LED65_W5_A0, LED65_W5_A1, LED65_W5_A2, LED65_W5_A3, LED65_W5_A4, LED65_W5_A5, LED66_W5_10, LED66_W5_11, LED66_W5_12, LED66_W5_13, LED66_W5_14, LED66_W5_15, LED66_W5_20, LED66_W5_21, LED66_W5_22, LED66_W5_23, LED66_W5_24, LED66_W5_25, LED66_W5_30, LED66_W5_31, LED66_W5_32, LED66_W5_33, LED66_W5_34, LED66_W5_35, LED66_W5_40, LED66_W5_41, LED66_W5_42, LED66_W5_43, LED66_W5_44, LED66_W5_45, LED66_W5_50, LED66_W5_51, LED66_W5_52, LED66_W5_53, LED66_W5_54, LED66_W5_55, LED66_W5_60, LED66_W5_61, LED66_W5_62, LED66_W5_63, LED66_W5_64, LED66_W5_65, LED66_W5_70, LED66_W5_71, LED66_W5_72, LED66_W5_73, LED66_W5_74, LED66_W5_75, LED66_W5_80, LED66_W5_81, LED66_W5_82, LED66_W5_83, LED66_W5_84, LED66_W5_85, LED66_W5_90, LED66_W5_91, LED66_W5_92, LED66_W5_93, LED66_W5_94, LED66_W5_95, LED66_W5_A0, LED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 | NF2W757GT-F1 |  |  |  | NF2W757GT-F1 | Nichia | NF2W757GT-F1

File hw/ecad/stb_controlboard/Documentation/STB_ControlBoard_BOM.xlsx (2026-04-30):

Quantity | Designator | Comment | Value | Tolerance | Power | Footprint | Manufacturer | Manufacturer Part Number
1 | FB1 | 80mR |  | 25% |  | MURA-BLM03-CHIP-2_V | Murata | BLM03AX800SN1D
1 | J1 | 2305018-2 |  |  |  | 2305018-2 | TE Connectivity | 2305018-2
1 | L1 | DFE201612E-2R2M=P2 | 2.2uH | ±20% |  | INDC2016X10L | Murata Electronics | DFE201612E-2R2M=P2
1 | LS1 | PKMCS0909E4000-R1 |  |  |  | MURA- PKMCS0909E4000-2_V | Murata | PKMCS0909E4000-R1
1 | P1 | TSW-120-24-L-D |  |  |  | SMTC-TSW-120-24-X-D | Samtec | TSW-120-24-L-D
1 | Q1 | SIA440DJ-T1-GE3 |  |  |  | SC70-6L_65P210X80_HS-7L | Vishay Siliconix | SIA440DJ-T1-GE3
1 | R3 | 1k | 1 kOhm | 1% |  | RESC1005X40X25LL05T10 | Yageo / Phycomp | RC0402FR-071KL
1 | R5 | 150k | 150 kOhm | 1% |  | RESC1005X40X25LL05T05 | Yageo | RC0402FR-07150KL
1 | R8 | 30R | 30 Ohm | 1% |  | RESC1609X50X30LL10T20 | Vishay Dale | CRCW060330R0FKEA
1 | R9 | 27R | 27 Ohm | 1% |  | RESC1608X55X30LL15T15 | Panasonic | ERJ-3EKF27R0V
1 | R11 | 1R | 1 Ohm | 1% |  | RESC3225X70X50NL20T20 | Panasonic | ERJ14BQF1R0U
1 | R14 | 1k | 1 kOhm | 1% |  | RESC3216X70X50LL05T20 | Panasonic | ERJ-8ENF1001V
1 | R52 | 820k | 820 kOhm | 1% |  | RESC1005X40X25LL05T05 | Vishay Dale | CRCW0402820KFKED
1 | SW1 | EVP-AA002K |  |  |  | PNSC-EVPAA_V | Panasonic | EVP-AA002K
1 | U1 | TPS2111APW |  |  |  | PW0008A_N | Texas Instruments | TPS2111APW
1 | U2 | TPS62160QDSGRQ1 |  |  |  | FP-DSG0008A-IPC_C | Texas Instruments | TPS62160QDSGRQ1
1 | U3 | STM32L452VEI6 |  |  |  | UFBGA100 | STMicroelectronics | STM32L452VEI6
1 | U4 | TPD4S009DRYR |  |  |  | DRY0006A | Texas Instruments | TPD4S009DRYR
1 | U6 | MAX6615AEE+T |  |  |  | MAXM-E16+1_M | Maxim | MAX6615AEE+T
1 | X10 | 3220-10-0100-00 |  |  |  | 3220-10-0100-00 | CNC Tech | 3220-10-0100-00
1 | Y1 | SiT1532AI-J4-DCC-32.768E |  |  |  | 4-UFBGA | SiTime | SiT1532AI-J4-DCC-32.768E
1 | Y2 | 8MHz |  |  |  | NDK-NX3225GD-8MHZ-STD-CRA-3_V | NDK | NX3225GD-8MHZ-STD-CRA-3
2 | C10, C11 | 16pF | 16pF |  |  | CAPC1005X55X25LL05T10 | Murata | GRM1555C1H160JA01D
2 | C18, C20 | 1uF | 1uF |  |  | CAPC1608X90X35LL15T15 | Kemet | C0603C105K4RACTU
2 | C26, C27 | 100pF | 100pF |  |  | CAPC1005X56X25LL10T15 | AVX Interconnect / Elco | 04023A101KAT2A
2 | L2, L3 | LI0402E300R-10 |  |  |  | INDC1005X07L | Laird-Signal Integrity Products | LI0402E300R-10
2 | M1, M2 | 1202713 |  |  |  | 1202713 | Phoenix Contact | 1202713
2 | R1, R2 | 470k | 470 kOhm | 1% |  | RESC1005X40X25LL05T10 | Yageo / Phycomp | RC0402FR-07470KL
2 | R6, R16 | 56R | 56 Ohm | 1% |  | RESC1609X50X30LL10T20 | Vishay Dale | CRCW060356R0FKEA
2 | R55, R56 | 5k1 | 5.1 kOhm | 1% |  | RESC1005X40X25LL05T10 | Yageo / Phycomp | RC0402FR-075K1L
2 | R65, R67 | 1k6 | 1.6 kOhm | 1% |  | RESC1005X40X25LL05T10 | Yageo / Phycomp | RC0402FR-071K6L
2 | R66, R68 | NCP15XH103F03RC | 10 kOhm | 1% |  | FP-NCP15-NCU15-0_05-IPC_C | Murata | NCP15XH103F03RC
2 | U5_E1, U5_E2 | TPS25200DRVT |  |  |  | FP-DRV0006A-MFG | Texas Instruments | TPS25200DRVT
2 | X5, X9 | 5103309-1 |  |  |  | TECO-5103309-1_V | TE Connectivity | 5103309-1
2 | X12, X13 | 3-647168-4 |  |  |  | 3-647168-4 | TE Connectivity | 3-647166-4
3 | X1, X7, X11 | 61202021621 |  |  |  | 61202021621 | Wurth Elektronik | 61202021621
3 | X8, X14, X15 | 2059-302/998-403 |  |  |  | 2059-302/998-403 | WAGO | 2059-302/998-403
4 | X2, X3, X4, X6 | 1760490000 |  |  |  | PM_5_08_90_02 | Weidmueller | 1760490000
5 | R48, R57_E1, R57_E2, R58_E1, R58_E2 | 390k | 390 kOhm | 1% |  | RESC1005X40X25LL05T05 | Panasonic | ERJ-2RKF3903X
7 | C3, C4, C5, C6, C7, C23_E1, C23_E2 | 10uF | 10uF | Â±10% |  | CAPC0603(1608)100_L | Samsung | CL10A106MP8NNNC
7 | R10, R34, R35, R36, R50, R63, R64 | 10k | 10 kOhm | 1% |  | RESC1005X40X25LL05T05 | Panasonic | ERJ-2RKF1002X
8 | R4, R7, R41, R42, R43, R44, R51, R53 | 100k | 100 kOhm | 1% |  | RESC1005X40X25LL05T10 | Yageo / Phycomp | RC0402FR-07100KL
10 | R27, R28, R31, R32, R37, R38, R59, R60, R61, R62 | 4k7 | 4.7 kOhm | 1% |  | RESC1005X40X25LL05T10 | Yageo / Phycomp | RC0402FR-074K7L
10 | R29, R30, R33, R39, R40, R45, R46, R47, R49, R54 | 0R | 0R |  |  | RESC1005X40X25LL05T10 | Yageo / Phycomp | RC0402JR-070RL
17 | C1, C2, C8, C9, C12, C13, C14, C15, C16, C17, C19, C21, C22_E1, C22_E2, C24_E1, C24_E2, C25 | 100nF | 100nF |  |  | CAPC1050X55X23LL05T13 | Samsung Electro-Mechanics | CL05B104KO5NNNC

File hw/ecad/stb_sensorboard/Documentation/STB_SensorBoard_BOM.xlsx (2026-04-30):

Quantity | Designator | Comment | Value | Tolerance | Power | Footprint | Manufacturer | Manufacturer Part Number
1 | D8 | ESD9C5.0ST5G |  |  |  | ONSC-SOD-923-2-514AB-01_V | On Semiconductor | ESD9C5.0ST5G
1 | D9 | ESD9X12ST5G |  |  |  | ONSC-SOD-923-2-514AA-01_V | On Semiconductor | ESD9X12ST5G
1 | L2 | LI0402E300R-10 |  |  |  | INDC1005X07L | Laird-Signal Integrity Products | LI0402E300R-10
1 | R5 | 200k | 200 kOhm | 1% |  | RESC1005X40X25LL05T10 | Yageo / Phycomp | RC0402FR-07200KL
1 | R8 | 560k | 560 kOhm | 1% |  | RESC1005X40X25LL05T05 | Panasonic | ERJ-2RKF5603X
1 | R37 | 1M | 1 MOhm | 1% |  | RESC1005X40X25LL05T10 | Yageo / Phycomp | RC0402FR-071ML
1 | U3 | PCA9646PW,118 |  |  |  | TSSOP-16_N | NXP Semiconductors | PCA9646PW,118
1 | U5 | MAX6615AEE+T |  |  |  | MAXM-E16+1_M | Maxim | MAX6615AEE+T
1 | U8 | VEML60311X00 |  |  |  | 6-SMD - No Thermal Pad_2 | Vishay | VEML60311X00
1 | U11 | AS72651-BLGT |  |  |  | FP-AS72651-BLGT-MFG | ams | AS72651-BLGT
1 | U12 | MX25L4006EZUI-12G |  |  |  | MXIC-USON-8_V | Macronix | MX25L4006EZUI-12G
1 | U13 | AS72653-BLGT |  |  |  | FP-AS72653-BLGT-MFG | ams | AS72653-BLGT
1 | U14 | AS72652-BLGT |  |  |  | FP-AS72652-BLGT-MFG | ams | AS72652-BLGT
1 | U15 | TPS25200DRVT |  |  |  | FP-DRV0006A-MFG | Texas Instruments | TPS25200DRVT
1 | U16 | N24S64BC4DYT3G |  |  |  | 4-WLCSP (0.77x0.77) | ON Semiconductor | N24S64BC4DYT3G
1 | X1 | 61002021121 |  |  |  | 61002021121 | Wurth Elektronik | 61002021121
1 | X2 | 1844317 |  |  |  | 1844317 | Phoenix Contact | 1844317
1 | X15 | 2199119-4 |  |  |  | 2199119-4 | TE Connectivity | 2199230-4
2 | C5, C11 | 1nF | 1 nF | 10% |  | CAPC1005X55X25ML5T10 | Murata | GRM155R71H102KA01D
2 | C26, C27 | 100pF | 100pF |  |  | CAPC1005X56X25LL10T15 | AVX Interconnect / Elco | 04023A101KAT2A
2 | R21, R23 | NCP15XH103F03RC | 10 kOhm | 1% |  | FP-NCP15-NCU15-0_05-IPC_C | Murata | NCP15XH103F03RC
2 | R22, R24 | 1k6 | 1.6 kOhm | 1% |  | RESC1005X40X25LL05T10 | Yageo / Phycomp | RC0402FR-071K6L
2 | U1, U2 | AD5593RBCPZ-RL7 |  |  |  | FP-CP-16-32-IPC_C | Analog Devices | AD5593RBCPZ-RL7
2 | X10, X11 | 3-647168-4 |  |  |  | 3-647168-4 | TE Connectivity | 3-647166-4
4 | L1_T1, L1_T2, L1_T3, L1_T4 | 744042001 | 1 µH | 30% |  | WE-TPC-4818-M | Wurth Electronics | 744042001
4 | R15, R16, R17, R18 | 4k7 | 4.7 kOhm | 1% |  | RESC1005X40X25LL05T10 | Yageo / Phycomp | RC0402FR-074K7L
4 | U4_T1, U4_T2, U4_T3, U4_T4 | MP8833GD-0000-Z |  |  |  | QFN40P200X300X100-16N | Monolithic Power Systems | MP8833GD-0000-Z
4 | U6, U7, U9, U10 | OPT3001DNPT |  |  |  | DNP0006A | Texas Instruments | OPT3001DNPT
4 | X4, X5, X7, X8 | 73412-0110 |  |  |  | MOLX-73412-0110_V | Molex | 73412-0110
5 | C30, C34, C36, C38, C39 | 1uF | 1uF |  |  | CAPC1608X90X35LL15T15 | Kemet | C0603C105K4RACTU
6 | R3, R4, R6, R9, R10, R36 | 100k | 100 kOhm | 1% |  | RESC1005X40X25LL05T10 | Yageo / Phycomp | RC0402FR-07100KL
7 | D1, D2, D3, D4, D5, D6, D7 | ESD9R3.3ST5G |  |  |  | ONSC-SOD-923-2-514AB-01_V | On Semiconductor | SZESD9R3.3ST5G
8 | X3, X6, X9_T1, X9_T2, X9_T3, X9_T4, X12, X13 | 2059-302/998-403 |  |  |  | 2059-302/998-403 | WAGO | 2059-302/998-403
22 | M1, M2, M3, M4, M5, M6, M7, M8, M9, M10, M11, M12, M13, M14, M15, M16, M17, M18, M19, M20, M21, M22 | 9774015243R |  |  |  | 9774015243R | Wurth Electronics | 9774015243R
25 | C1, C2, C3, C4, C7, C8, C9, C10, C18_T1, C18_T2, C18_T3, C18_T4, C19_T1, C19_T2, C19_T3, C19_T4, C20_T1, C20_T2, C20_T3, C20_T4, C21_T1, C21_T2, C21_T3, C21_T4, C42 | 10uF | 10uF | Â±10% |  | CAPC0603(1608)100_L | Samsung | CL10A106MP8NNNC
25 | R2, R7, R11, R12_T1, R12_T2, R12_T3, R12_T4, R13_T1, R13_T2, R13_T3, R13_T4, R14_T1, R14_T2, R14_T3, R14_T4, R19, R20, R25, R26, R27, R28, R29, R30, R33, R34 | 10k | 10 kOhm | 1% |  | RESC1005X40X25LL05T05 | Panasonic | ERJ-2RKF1002X
33 | C6, C12, C13, C14, C15, C16, C17, C22_T1, C22_T2, C22_T3, C22_T4, C23_T1, C23_T2, C23_T3, C23_T4, C24_T1, C24_T2, C24_T3, C24_T4, C25, C28, C29, C31, C32, C33, C35, C37, C40, C41, C43, C44, C45, C46 | 100nF | 100nF |  |  | CAPC1050X55X23LL05T13 | Samsung Electro-Mechanics | CL05B104KO5NNNC

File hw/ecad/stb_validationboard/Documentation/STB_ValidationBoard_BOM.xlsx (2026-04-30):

Quantity | Designator | Comment | Value | Tolerance | Power | Footprint | Manufacturer | Manufacturer Part Number
1 | R9 | 976k | 976 kOhm | 1% |  | RESC1005X40X25LL05T05 | Panasonic | ERJ-2RKF9763X
1 | R10 | 102k | 102 kOhm | 1% |  | RESC1005X40X25LL05T05 | Panasonic | ERJ-2RKF1023X
1 | R11 | 200k | 200 kOhm | 1% |  | RESC1005X40X25LL05T10 | Yageo / Phycomp | RC0402FR-07200KL
1 | SW1 | DNP |  |  |  | PNSC-EVPAA_V | Panasonic | EVP-AA002K
1 | U3 | AS72651-BLGT |  |  |  | FP-AS72651-BLGT-MFG | ams | AS72651-BLGT
1 | U4 | MX25L4006EZUI-12G |  |  |  | MXIC-USON-8_V | Macronix | MX25L4006EZUI-12G
1 | U5 | AS72653-BLGT |  |  |  | FP-AS72653-BLGT-MFG | ams | AS72653-BLGT
1 | U6 | AS72652-BLGT |  |  |  | FP-AS72652-BLGT-MFG | ams | AS72652-BLGT
1 | U7 | N24S64BC4DYT3G |  |  |  | 4-WLCSP (0.77x0.77) | ON Semiconductor | N24S64BC4DYT3G
1 | U8 | LTC4316IDD#TRPBF |  |  |  | DFN10(3x3)_N | Analog Devices / Linear Technology | LTC4316IDD#TRPBF
2 | R7, R8 | 4k7 | 4.7 kOhm | 1% |  | RESC1005X40X25LL05T10 | Yageo / Phycomp | RC0402FR-074K7L
3 | R1, R4, R5 | 10k | 10 kOhm | 1% |  | RESC1005X40X25LL05T05 | Panasonic | ERJ-2RKF1002X
4 | C2, C4, C6, C8 | 1uF | 1uF |  |  | CAPC1608X90X35LL15T15 | Kemet | C0603C105K4RACTU
4 | U9, U10, U11, U12 | PCA9555AHF,128 |  |  |  | RGE0024C | NXP Semiconductors | PCA9555AHF,128
64 | U1_S1, U1_S2, U1_S3, U1_S4, U1_S5, U1_S6, U1_S7, U1_S8, U1_S9, U1_S10, U1_S11, U1_S12, U1_S13, U1_S14, U1_S15, U1_S16, U1_S17, U1_S18, U1_S19, U1_S20, U1_S21, U1_S22, U1_S23, U1_S24, U1_S25, U1_S26, U1_S27, U1_S28, U1_S29, U1_S30, U1_S31, U1_S32, U1_S33, U1_S34, U1_S35, U1_S36, U1_S37, U1_S38, U1_S39, U1_S40, U1_S41, U1_S42, U1_S43, U1_S44, U1_S45, U1_S46, U1_S47, U1_S48, U1_S49, U1_S50, U1_S51, U1_S52, U1_S53, U1_S54, U1_S55, U1_S56, U1_S57, U1_S58, U1_S59, U1_S60, U1_S61, U1_S62, U1_S63, U1_S64 | VEML60311X00 |  |  |  | 6-SMD - No Thermal Pad_2 | Vishay | VEML60311X00
65 | U2_S1, U2_S2, U2_S3, U2_S4, U2_S5, U2_S6, U2_S7, U2_S8, U2_S9, U2_S10, U2_S11, U2_S12, U2_S13, U2_S14, U2_S15, U2_S16, U2_S17, U2_S18, U2_S19, U2_S20, U2_S21, U2_S22, U2_S23, U2_S24, U2_S25, U2_S26, U2_S27, U2_S28, U2_S29, U2_S30, U2_S31, U2_S32, U2_S33, U2_S34, U2_S35, U2_S36, U2_S37, U2_S38, U2_S39, U2_S40, U2_S41, U2_S42, U2_S43, U2_S44, U2_S45, U2_S46, U2_S47, U2_S48, U2_S49, U2_S50, U2_S51, U2_S52, U2_S53, U2_S54, U2_S55, U2_S56, U2_S57, U2_S58, U2_S59, U2_S60, U2_S61, U2_S62, U2_S63, U2_S64, U13 | TMP116NAIDRVR |  |  |  | FP-DRV0006B-MFG | Texas Instruments | TMP116NAIDRVR
76 | C1_S1, C1_S2, C1_S3, C1_S4, C1_S5, C1_S6, C1_S7, C1_S8, C1_S9, C1_S10, C1_S11, C1_S12, C1_S13, C1_S14, C1_S15, C1_S16, C1_S17, C1_S18, C1_S19, C1_S20, C1_S21, C1_S22, C1_S23, C1_S24, C1_S25, C1_S26, C1_S27, C1_S28, C1_S29, C1_S30, C1_S31, C1_S32, C1_S33, C1_S34, C1_S35, C1_S36, C1_S37, C1_S38, C1_S39, C1_S40, C1_S41, C1_S42, C1_S43, C1_S44, C1_S45, C1_S46, C1_S47, C1_S48, C1_S49, C1_S50, C1_S51, C1_S52, C1_S53, C1_S54, C1_S55, C1_S56, C1_S57, C1_S58, C1_S59, C1_S60, C1_S61, C1_S62, C1_S63, C1_S64, C3, C5, C7, C9, C10, C11, C12, C13, C14, C15, C16, C17 | 100nF | 100nF |  |  | CAPC1050X55X23LL05T13 | Samsung Electro-Mechanics | CL05B104KO5NNNC

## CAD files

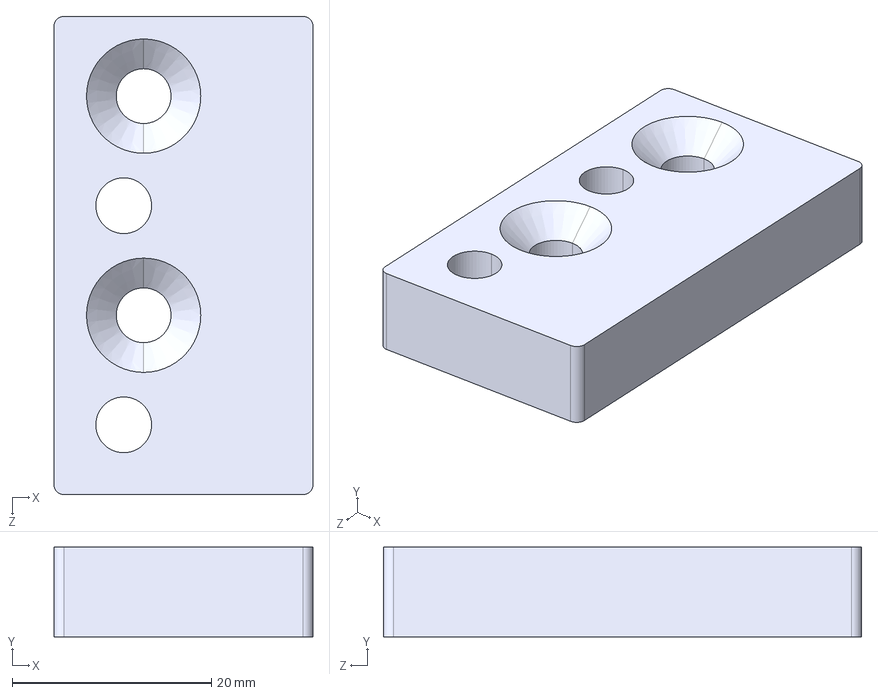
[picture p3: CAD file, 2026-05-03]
hw/mcad/3d_model/stb_door_sensor_magnet.STEP
26.0 x 9.00 x 48.0 mm

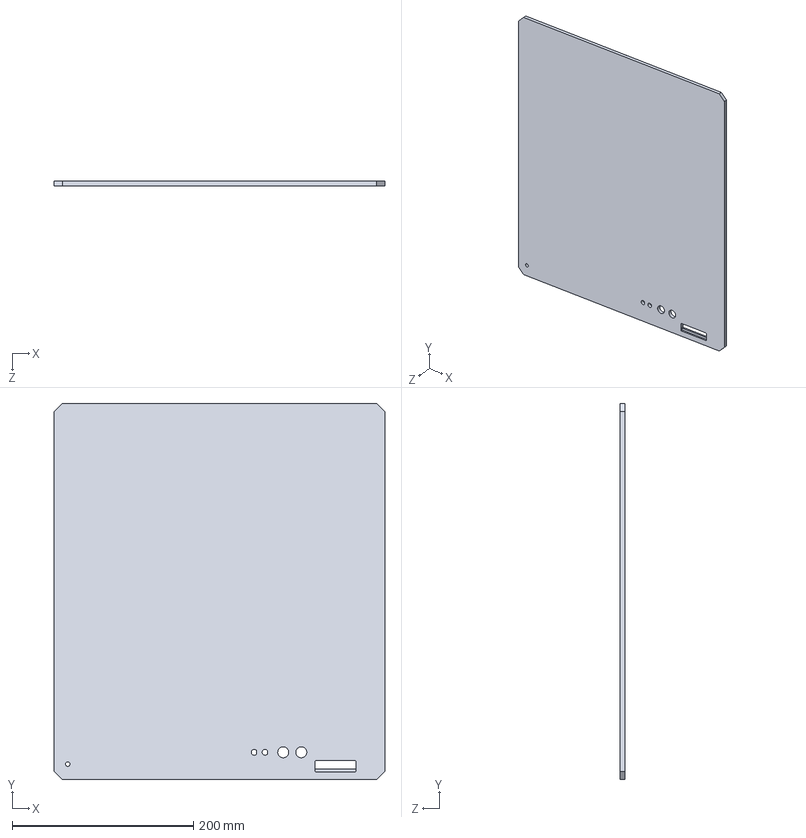
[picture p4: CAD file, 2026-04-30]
hw/mcad/3d_model/stb_wall_right.STEP
365.0 x 415.0 x 5.00 mm

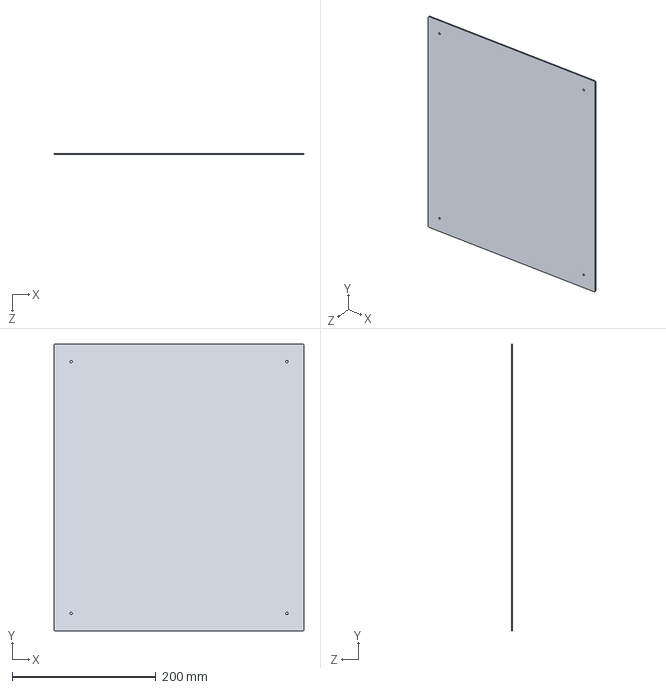
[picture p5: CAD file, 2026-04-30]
hw/mcad/3d_model/stb_door_reflector.STEP
347.0 x 399.0 x 2.00 mm

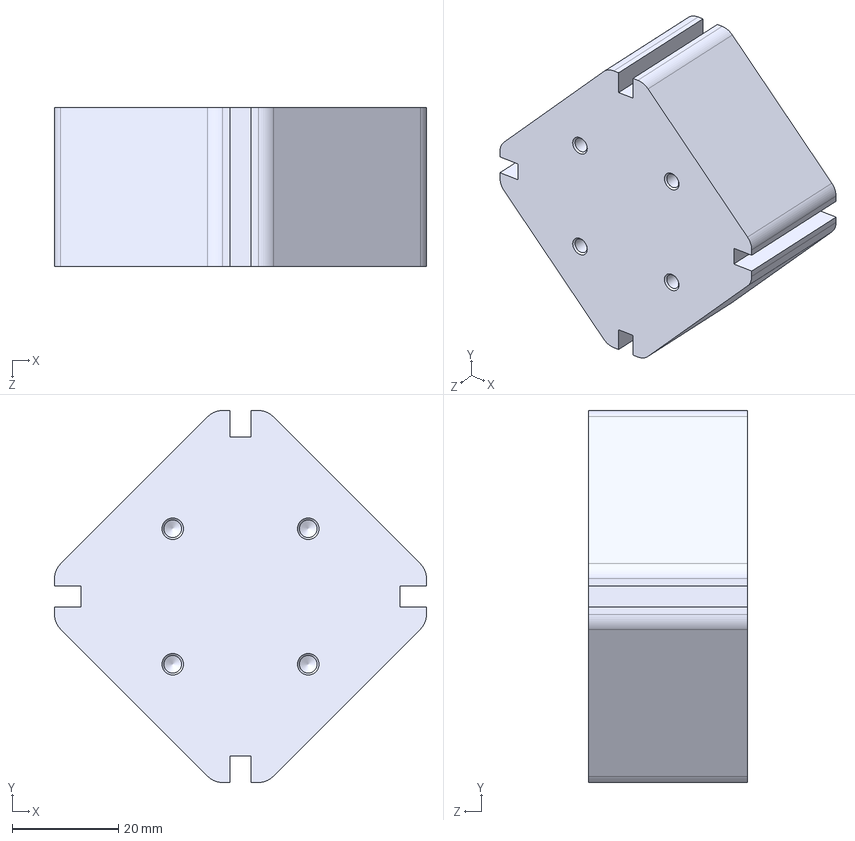
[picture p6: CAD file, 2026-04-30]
hw/mcad/3d_model/stb_fan_socket_center.STEP
70.0 x 70.0 x 30.0 mm

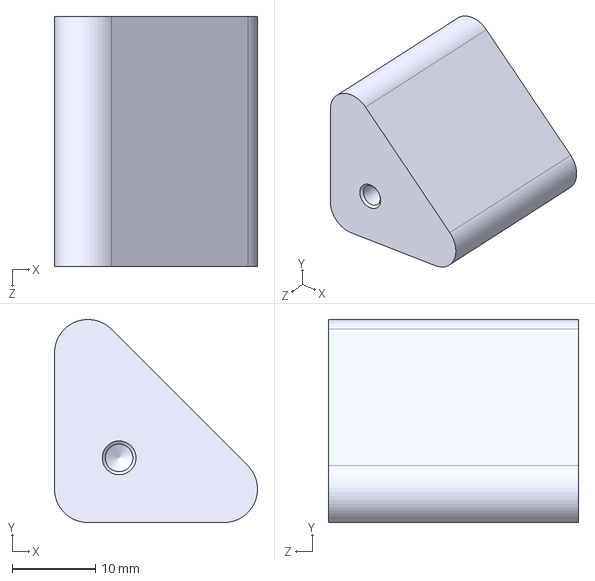
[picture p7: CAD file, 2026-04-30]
hw/mcad/3d_model/stb_fan_socket_corner.STEP
24.3 x 24.3 x 30.0 mm

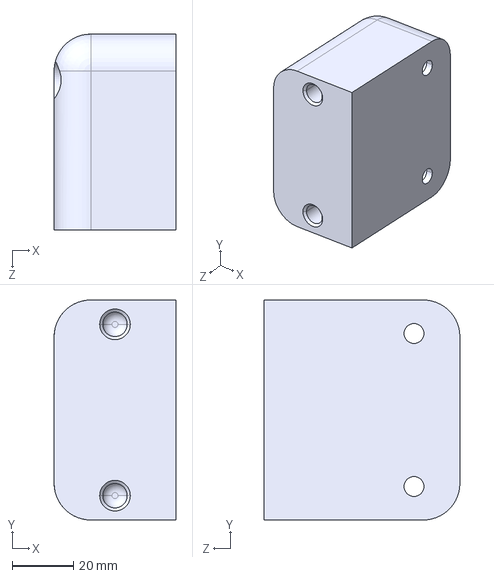
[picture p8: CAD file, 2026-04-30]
hw/mcad/3d_model/stb_closing_adapter.STEP
39.8 x 71.9 x 64.0 mm

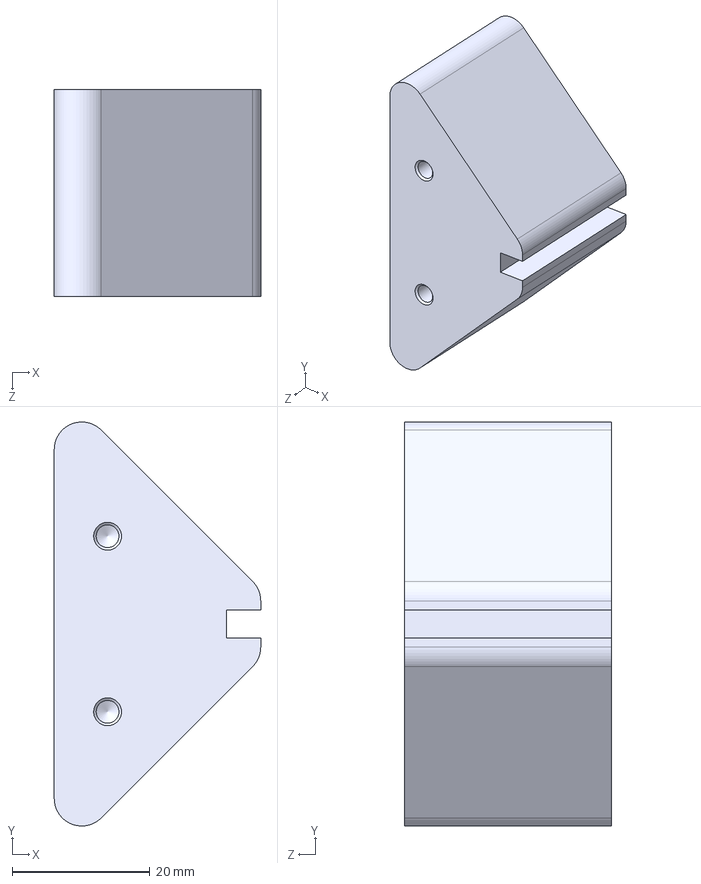
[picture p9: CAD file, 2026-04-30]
hw/mcad/3d_model/stb_fan_socket_side.STEP
30.0 x 58.7 x 30.0 mm

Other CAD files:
hw/mcad/3d_model/stb_door_sensor_bcd6.STEP
hw/mcad/3d_model/stb_door_wall.STEP
hw/mcad/3d_model/stb_wall_back.STEP
hw/mcad/3d_model/stb_wall_door.STEP
hw/mcad/3d_model/stb_wall_left.STEP

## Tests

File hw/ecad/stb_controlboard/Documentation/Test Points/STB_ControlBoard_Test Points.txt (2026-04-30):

Net         Name        X Coord     Y Coord     Side        Hole Size   Type        
SPI_CAM_MOSITP49-TP      41.6208mm   28.6548mm  Top                0mm  Surface mount
ADC1_IN1    TP41-TP      42.0793mm   50.6124mm  Top                0mm  Surface mount
ADC1_IN2    TP45-TP      49.9804mm   50.6699mm  Top                0mm  Surface mount
ADC1_IN4    TP54-TP      50.1957mm   76.8457mm  Top                0mm  Surface mount
NetC3_2     TP1-TP       47.3939mm   55.9581mm  Top                0mm  Surface mount
GND         TP3-TP       47.4675mm   51.7464mm  Top                0mm  Surface mount
NetC5_2     TP2-TP       40.7167mm   58.3261mm  Top                0mm  Surface mount
GND         TP4-TP        44.621mm   58.3495mm  Top                0mm  Surface mount
UART_RBI_RX TP28-TP      31.9375mm    61.674mm  Top                0mm  Surface mount
UART_RBI_TX TP27-TP        31.85mm   59.0258mm  Top                0mm  Surface mount
UART_RBI_TX TP48-TP      64.1783mm   24.1198mm  Top                0mm  Surface mount
SPI_CAM_CLK TP52-TP      40.6213mm   31.5512mm  Top                0mm  Surface mount
SPI_CAM_nCS TP53-TP      43.6335mm   25.3171mm  Top                0mm  Surface mount
GPIO_BUZZER TP29-TP      49.3685mm      65.4mm  Top                0mm  Surface mount
GND         TP30-TP      56.1038mm   76.8457mm  Top                0mm  Surface mount
24V         TP34-TP      44.7353mm   77.0115mm  Top                0mm  Surface mount
UART_SYS_TX TP43-TP       58.403mm   13.5379mm  Top                0mm  Surface mount
UART_LIGHT_RXTP44-TP        22.81mm   29.8535mm  Top                0mm  Surface mount
UART_LIGHT_TXTP46-TP      43.7151mm   38.7695mm  Top                0mm  Surface mount
UART_RBI_RX TP47-TP      60.7013mm   30.8698mm  Top                0mm  Surface mount
SPI_CAM_MISOTP51-TP      40.7167mm   33.2583mm  Bottom             0mm  Surface mount
I2C_CAM_SCL TP39-TP       64.761mm   63.2118mm  Bottom             0mm  Surface mount
3V3_LIGHT_ENTP11-TP      16.7561mm   70.6033mm  Bottom             0mm  Surface mount
3V3         TP31-TP         16.8mm   72.8359mm  Bottom             0mm  Surface mount
3V3_LIGHT_nFAULTTP12-TP      16.7561mm   74.5133mm  Bottom             0mm  Surface mount
I2C_LIGHT_SDATP8-TP         17.73mm      87.7mm  Bottom             0mm  Surface mount
UART_LIGHT_RXTP9-TP         15.19mm      87.7mm  Bottom             0mm  Surface mount
UART_LIGHT_TXTP10-TP        12.65mm      87.7mm  Bottom             0mm  Surface mount
INT_DOOR    TP14-TP        25.35mm       2.5mm  Bottom             0mm  Surface mount
GPIO1       TP13-TP        25.35mm     8.675mm  Bottom             0mm  Surface mount
INT_VEML    TP16-TP        22.81mm       2.5mm  Bottom             0mm  Surface mount
GPIO2       TP15-TP        22.81mm     8.385mm  Bottom             0mm  Surface mount
INT_AS7265x TP18-TP        20.27mm       2.5mm  Bottom             0mm  Surface mount
INT_TMP     TP20-TP        17.73mm       2.5mm  Bottom             0mm  Surface mount
INT_MAX6615_nOTTP22-TP        15.19mm       2.5mm  Bottom             0mm  Surface mount
UART_SYS_RX TP21-TP       15.201mm    8.3613mm  Bottom             0mm  Surface mount
INT_MAX6615_nFAILTP24-TP        12.65mm       2.5mm  Bottom             0mm  Surface mount
UART_SYS_TX TP23-TP        12.65mm     8.385mm  Bottom             0mm  Surface mount
I2C_SYS_SCL TP17-TP        20.27mm        10mm  Bottom             0mm  Surface mount
I2C_SYS_SDA TP19-TP        17.73mm      10.2mm  Bottom             0mm  Surface mount
3V3_SYS_EN  TP25-TP      15.6529mm    18.375mm  Bottom             0mm  Surface mount
3V3_SYS_nFAULTTP26-TP      15.6529mm      16.1mm  Bottom             0mm  Surface mount
5V          TP32-TP        30.43mm       8.6mm  Bottom             0mm  Surface mount
12V         TP33-TP         7.57mm       8.6mm  Bottom             0mm  Surface mount
GPIO3       TP5-TP         25.35mm      87.7mm  Bottom             0mm  Surface mount
GPIO4       TP6-TP         22.81mm      87.7mm  Bottom             0mm  Surface mount
I2C_LIGHT_SCLTP7-TP         20.27mm      87.7mm  Bottom             0mm  Surface mount
I2C_CAM_SDA TP40-TP      66.7858mm      64.9mm  Bottom             0mm  Surface mount
ADC1_IN3    TP50-TP      48.7341mm   20.8833mm  Bottom             0mm  Surface mount

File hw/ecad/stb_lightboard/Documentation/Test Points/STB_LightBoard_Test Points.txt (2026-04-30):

Net         Name        X Coord     Y Coord     Side        Hole Size   Type        
NetR48_TC1_1TP1-TP         265.4mm     305.9mm  Top                0mm  Surface mount
NetR48_TC2_1TP2-TP          23.8mm       -16mm  Top                0mm  Surface mount

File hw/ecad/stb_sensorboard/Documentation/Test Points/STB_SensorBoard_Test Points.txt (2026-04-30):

Net         Name        X Coord     Y Coord     Side        Hole Size   Type        
NetC16_2    TP22-TP     188.3178mm     297.1mm  Top                0mm  Surface mount
NetR28_1    TP31-TP           52mm     295.5mm  Top                0mm  Surface mount
CELL_POS    TP17-TP     340.2128mm     271.5mm  Top                0mm  Surface mount
CELL_NEG    TP16-TP     340.2128mm     268.5mm  Top                0mm  Surface mount
5V          TP1-TP        267.43mm  345.0024mm  Top                0mm  Surface mount
3V3         TP10-TP       244.57mm       345mm  Top                0mm  Surface mount
GND         TP15-TP       264.89mm  345.0074mm  Top                0mm  Surface mount
NetR2_1     TP19-TP      158.225mm     303.2mm  Top                0mm  Surface mount
NetC14_2    TP20-TP     156.8245mm  295.5938mm  Top                0mm  Surface mount
INT_DOOR    TP3-TP        262.35mm       345mm  Top                0mm  Surface mount
GPIO2       TP4-TP      258.5537mm  344.0083mm  Top                0mm  Surface mount
INT_VEML    TP5-TP        259.81mm       345mm  Top                0mm  Surface mount
I2C_SYS_SCL TP6-TP      255.9999mm       344mm  Top                0mm  Surface mount
I2C_SYS_SDA TP8-TP         253.4mm       344mm  Top                0mm  Surface mount
UART_SYS_TX TP13-TP     248.3811mm  343.9971mm  Top                0mm  Surface mount
INT_MAX6615_nFAILTP14-TP       249.65mm       345mm  Top                0mm  Surface mount
UART_SYS_RX TP11-TP          251mm       344mm  Top                0mm  Surface mount
INT_MAX6615_nOTTP12-TP     252.2405mm       345mm  Top                0mm  Surface mount
INT_TMP     TP9-TP        254.73mm       345mm  Top                0mm  Surface mount
INT_AS7265x TP7-TP        257.27mm       345mm  Top                0mm  Surface mount
NetR11_2    TP24-TP     166.8951mm  301.1431mm  Top                0mm  Surface mount
NetR7_1     TP21-TP     181.9228mm  297.0892mm  Top                0mm  Surface mount
VDUT        TP23-TP     182.6728mm  301.3664mm  Top                0mm  Surface mount
PELTIER_VO1_T3TP26_T3-TP     298.1mm     128.5mm  Top                0mm  Surface mount
PELTIER_VOS_T3TP25_T3-TP     298.1mm  131.5001mm  Top                0mm  Surface mount
PELTIER_VO1_T1TP26_T1-TP   45.8286mm  217.9862mm  Top                0mm  Surface mount
PELTIER_VOS_T1TP25_T1-TP   45.8286mm  214.9862mm  Top                0mm  Surface mount
NetR26_1    TP30-TP        298.8mm     295.5mm  Top                0mm  Surface mount
NetR25_1    TP29-TP       50.879mm      46.5mm  Top                0mm  Surface mount
NetR29_1    TP32-TP     297.6625mm     50.65mm  Top                0mm  Surface mount
PELTIER_VO1_T4TP26_T4-TP  298.1867mm       229mm  Top                0mm  Surface mount
PELTIER_VOS_T4TP25_T4-TP  298.1867mm       232mm  Top                0mm  Surface mount
GPIO1       TP2-TP       261.097mm  344.0083mm  Top                0mm  Surface mount
PELTIER_VO1_T2TP26_T2-TP    45.656mm  117.5297mm  Top                0mm  Surface mount
PELTIER_VOS_T2TP25_T2-TP    45.656mm  114.5297mm  Top                0mm  Surface mount
INT_DOOR    TP18-TP        350.5mm      16.3mm  Top                0mm  Surface mount

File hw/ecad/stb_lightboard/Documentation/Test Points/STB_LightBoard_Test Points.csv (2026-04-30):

Net | Name | X Coord | Y Coord | Side | Hole Size | Type
NetR48_TC1_1 | TP1-TP | 265.4mm | 305.9mm | Top | 0mm | Surface mount
NetR48_TC2_1 | TP2-TP | 23.8mm | -16mm | Top | 0mm | Surface mount

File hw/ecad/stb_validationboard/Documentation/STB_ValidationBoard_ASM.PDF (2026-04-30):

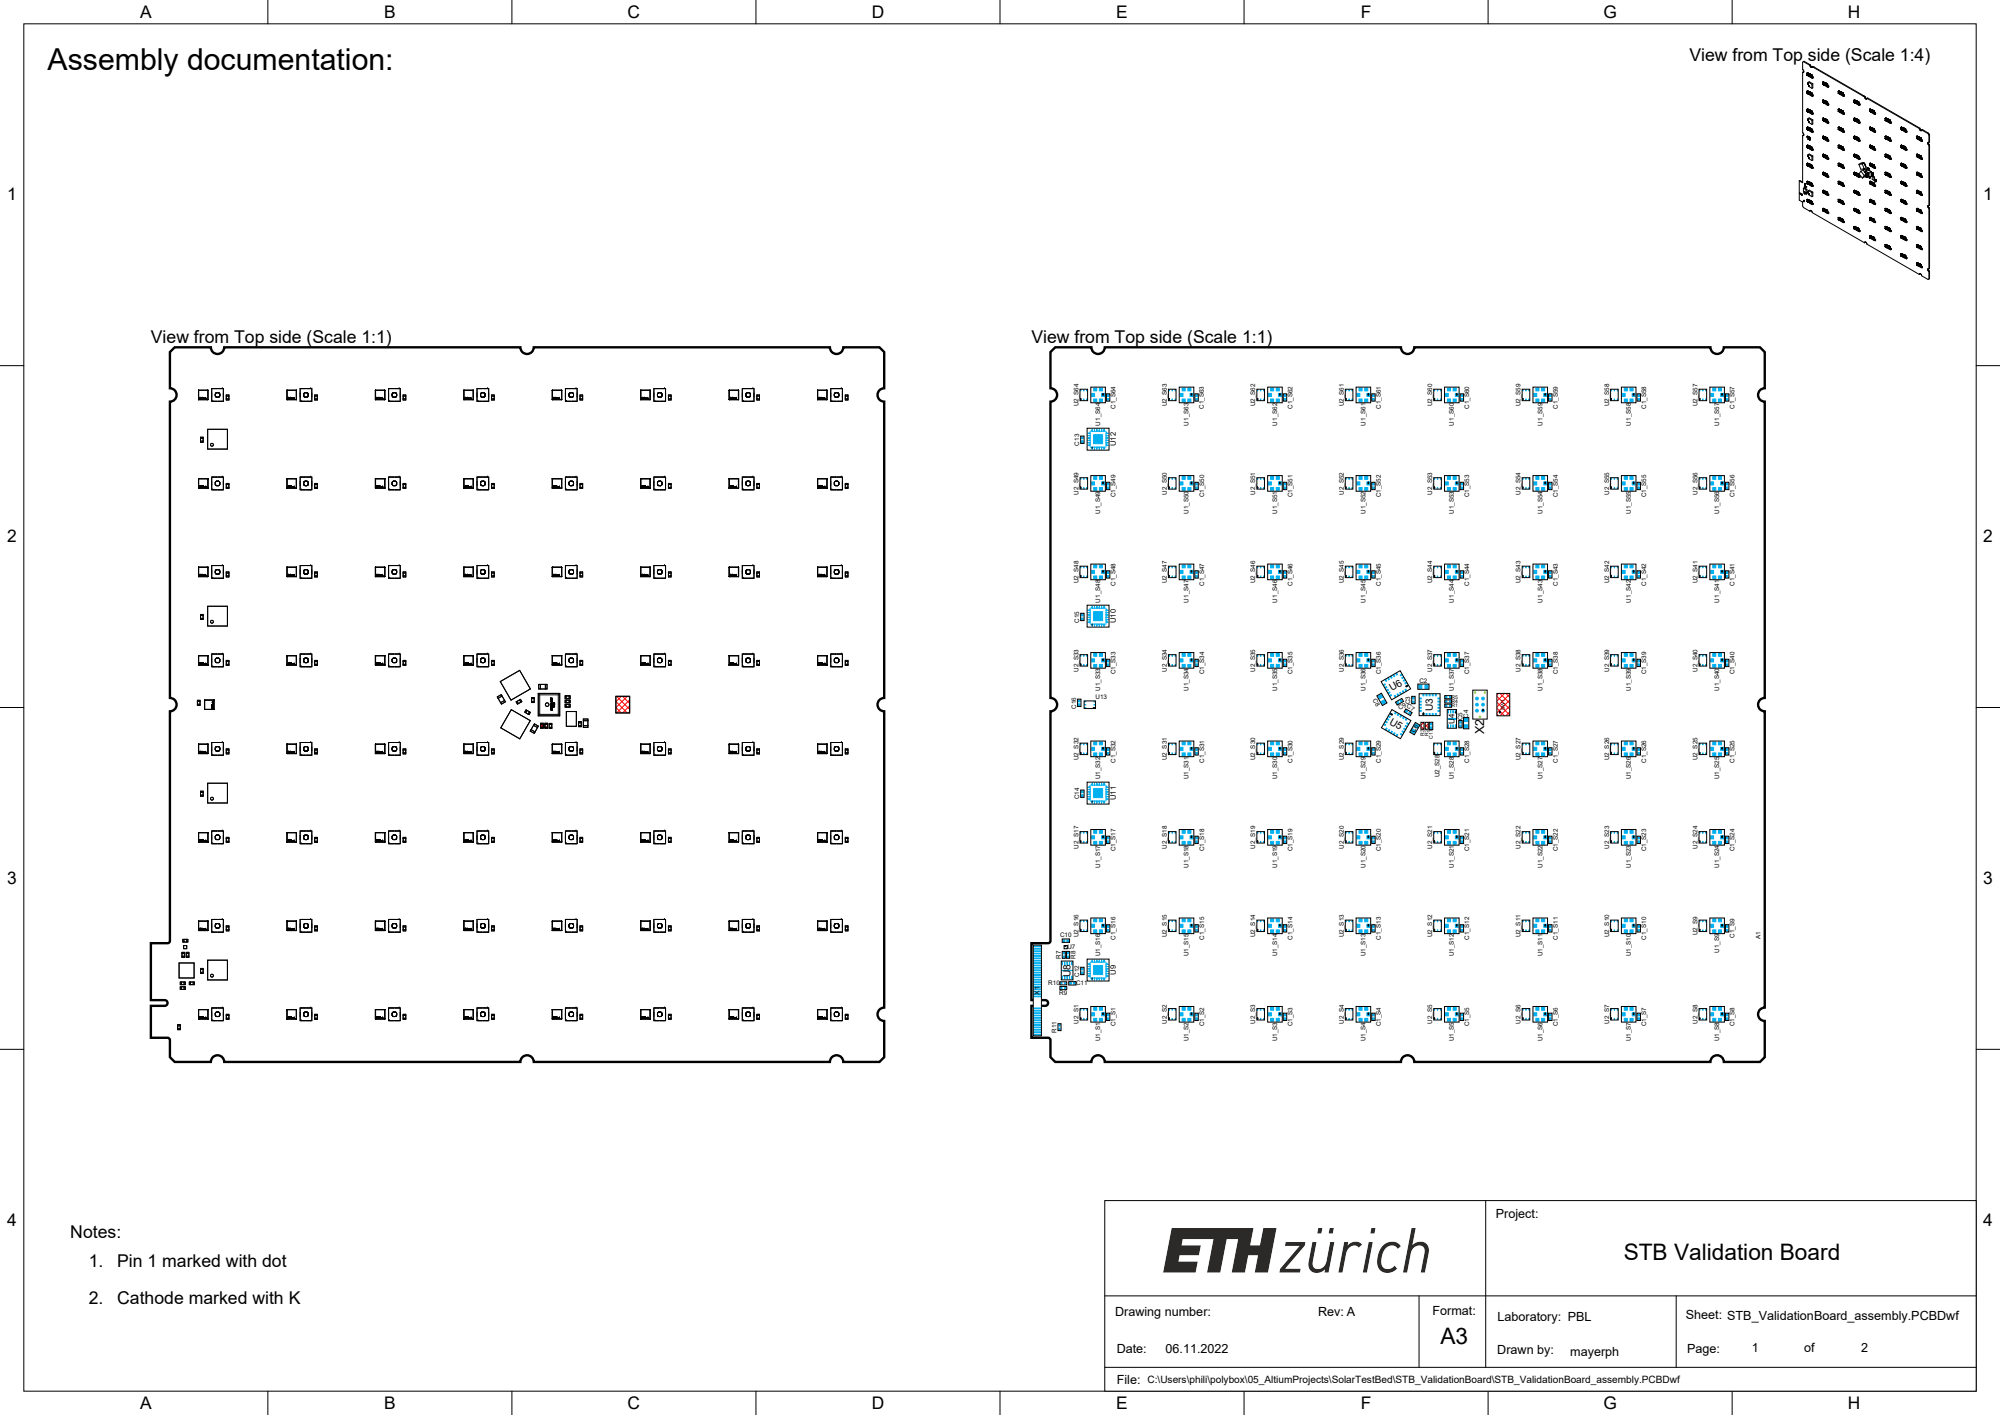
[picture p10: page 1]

View from Top side (Scale 1:4)

Notes:
1. Pin 1 marked with dot

File:
C:\Users\phili\polybox\05_AltiumProjects\SolarTestBed\STB_ValidationBoard\STB_ValidationBoard_assembly.PCBDwf

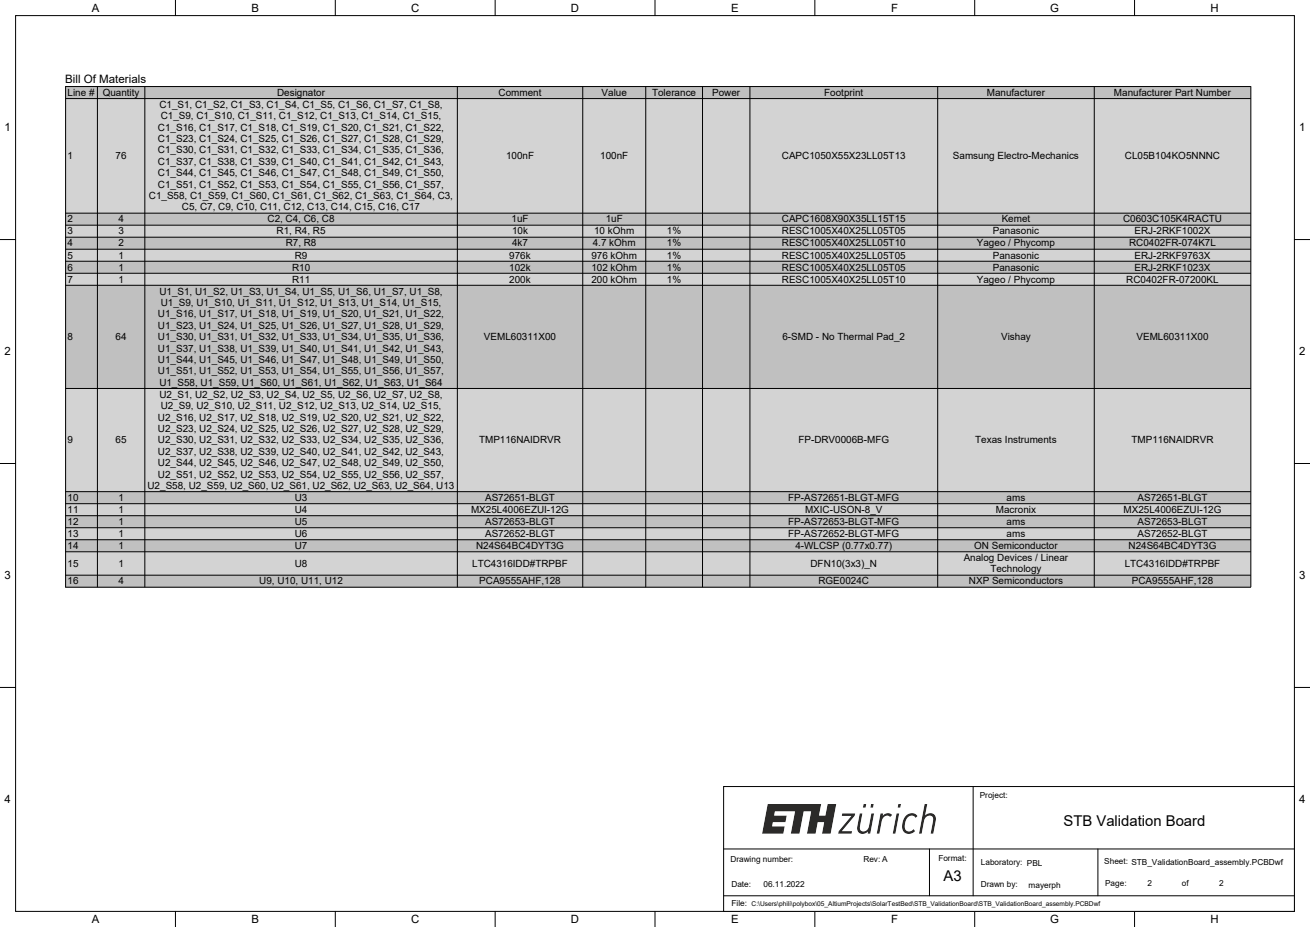
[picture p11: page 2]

Line # | Quantity | Designator | Comment | Value | Tolerance | Power | Footprint | Manufacturer | Manufacturer Part Number
1 | 76 | C1_S1, C1_S2, C1_S3, C1_S4, C1_S5, C1_S6, C1_S7, C1_S8, C1_S9, C1_S10, C1_S11, C1_S12, C1_S13, C1_S14, C1_S15, C1_S16, C1_S17, C1_S18, C1_S19, C1_S20, C1_S21, C1_S22, C1_S23, C1_S24, C1_S25, C1_S26, C1_S27, C1_S28, C1_S29, C1_S30, C1_S31, C1_S32, C1_S33, C1_S34, C1_S35, C1_S36, C1_S37, C1_S38, C1_S39, C1_S40, C1_S41, C1_S42, C1_S43, C1_S44, C1_S45, C1_S46, C1_S47, C1_S48, C1_S49, C1_S50, C1_S51, C1_S52, C1_S53, C1_S54, C1_S55, C1_S56, C1_S57, C1_S58, C1_S59, C1_S60, C1_S61, C1_S62, C1_S63, C1_S64, C3, C5, C7, C9, C10, C11, C12, C13, C14, C15, C16, C17 | 100nF | 100nF | | | CAPC1050X55X23LL05T13 | Samsung Electro-Mechanics | CL05B104KO5NNNC

2 | 4 | C2, C4, C6, C8 | 1uF | 1uF | | | CAPC1608X90X35LL15T15 | Kemet | C0603C105K4RACTU
3 | 3 | R1, R4, R5 | 10k | 10 kOhm | 1% | | RESC1005X40X25LL05T05 | Panasonic | ERJ-2RKF1002X
4 | 2 | R7, R8 | 4k7 | 4.7 kOhm | 1% | | RESC1005X40X25LL05T10 | Yageo / Phycomp | RC0402FR-074K7L
5 | 1 | R9 | 976k | 976 kOhm | 1% | | RESC1005X40X25LL05T05 | Panasonic | ERJ-2RKF9763X
6 | 1 | R10 | 102k | 102 kOhm | 1% | | RESC1005X40X25LL05T05 | Panasonic | ERJ-2RKF1023X
7 | 1 | R11 | 200k | 200 kOhm | 1% | | RESC1005X40X25LL05T10 | Yageo / Phycomp | RC0402FR-07200KL
8 | 64 | U1_S1, U1_S2, U1_S3, U1_S4, U1_S5, U1_S6, U1_S7, U1_S8, U1_S9, U1_S10, U1_S11, U1_S12, U1_S13, U1_S14, U1_S15, U1_S16, U1_S17, U1_S18, U1_S19, U1_S20, U1_S21, U1_S22, U1_S23, U1_S24, U1_S25, U1_S26, U1_S27, U1_S28, U1_S29, U1_S30, U1_S31, U1_S32, U1_S33, U1_S34, U1_S35, U1_S36, U1_S37, U1_S38, U1_S39, U1_S40, U1_S41, U1_S42, U1_S43, U1_S44, U1_S45, U1_S46, U1_S47, U1_S48, U1_S49, U1_S50, U1_S51, U1_S52, U1_S53, U1_S54, U1_S55, U1_S56, U1_S57, U1_S58, U1_S59, U1_S60, U1_S61, U1_S62, U1_S63, U1_S64 | VEML60311X00 | | | | 6-SMD - No Thermal Pad_2 | Vishay | VEML60311X00

9 | 65 | U2_S1, U2_S2, U2_S3, U2_S4, U2_S5, U2_S6, U2_S7, U2_S8, U2_S9, U2_S10, U2_S11, U2_S12, U2_S13, U2_S14, U2_S15, U2_S16, U2_S17, U2_S18, U2_S19, U2_S20, U2_S21, U2_S22, U2_S23, U2_S24, U2_S25, U2_S26, U2_S27, U2_S28, U2_S29, U2_S30, U2_S31, U2_S32, U2_S33, U2_S34, U2_S35, U2_S36, U2_S37, U2_S38, U2_S39, U2_S40, U2_S41, U2_S42, U2_S43, U2_S44, U2_S45, U2_S46, U2_S47, U2_S48, U2_S49, U2_S50, U2_S51, U2_S52, U2_S53, U2_S54, U2_S55, U2_S56, U2_S57, U2_S58, U2_S59, U2_S60, U2_S61, U2_S62, U2_S63, U2_S64, U13 | TMP116NAIDRVR | | | | FP-DRV0006B-MFG | Texas Instruments | TMP116NAIDRVR

10 | 1 | U3 | AS72651-BLGT | | | | FP-AS72651-BLGT-MFG | ams | AS72651-BLGT
11 | 1 | U4 | MX25L4006EZUI-12G | | | | MXIC-USON-8_V | Macronix | MX25L4006EZUI-12G
12 | 1 | U5 | AS72653-BLGT | | | | FP-AS72653-BLGT-MFG | ams | AS72653-BLGT
13 | 1 | U6 | AS72652-BLGT | | | | FP-AS72652-BLGT-MFG | ams | AS72652-BLGT
14 | 1 | U7 | N24S64BC4DYT3G | | | | 4-WLCSP (0.77x0.77) | ON Semiconductor | N24S64BC4DYT3G
15 | 1 | U8 | LTC4316IDD#TRPBF | | | | DFN10(3x3)_N | Analog Devices / Linear Technology | LTC4316IDD#TRPBF

16 | 4 | U9, U10, U11, U12 | PCA9555AHF,128 | | | | RGE0024C | NXP Semiconductors | PCA9555AHF,128

Project: STB Validation Board

Drawing number: Rev: A Date: 06.11.2022 | Format: | Laboratory: PBL Drawn by: mayerph | Sheet: STB_ValidationBoard_assembly.PCBDwf of A3 Page: 2 2

File:
C:\Users\phili\polybox\05_AltiumProjects\SolarTestBed\STB_ValidationBoard\STB_ValidationBoard_assembly.PCBDwf

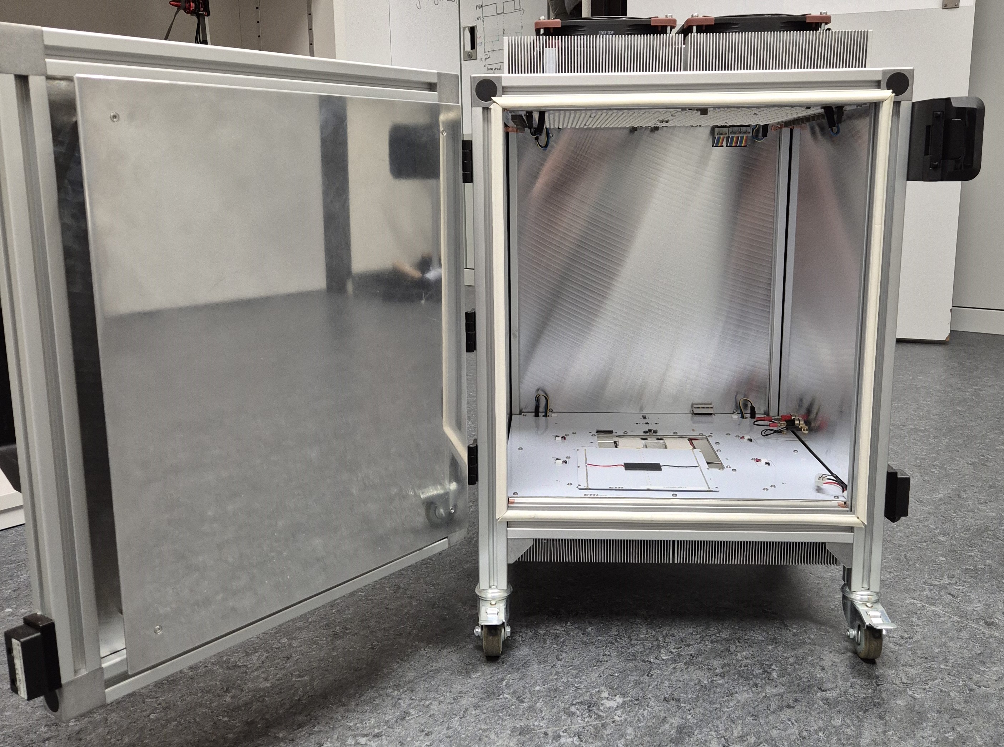
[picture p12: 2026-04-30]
doc/images/solar_testbed.jpg

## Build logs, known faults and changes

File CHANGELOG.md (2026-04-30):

# Changelog

## Version 1.0 (30.04.2026)
- Inital version

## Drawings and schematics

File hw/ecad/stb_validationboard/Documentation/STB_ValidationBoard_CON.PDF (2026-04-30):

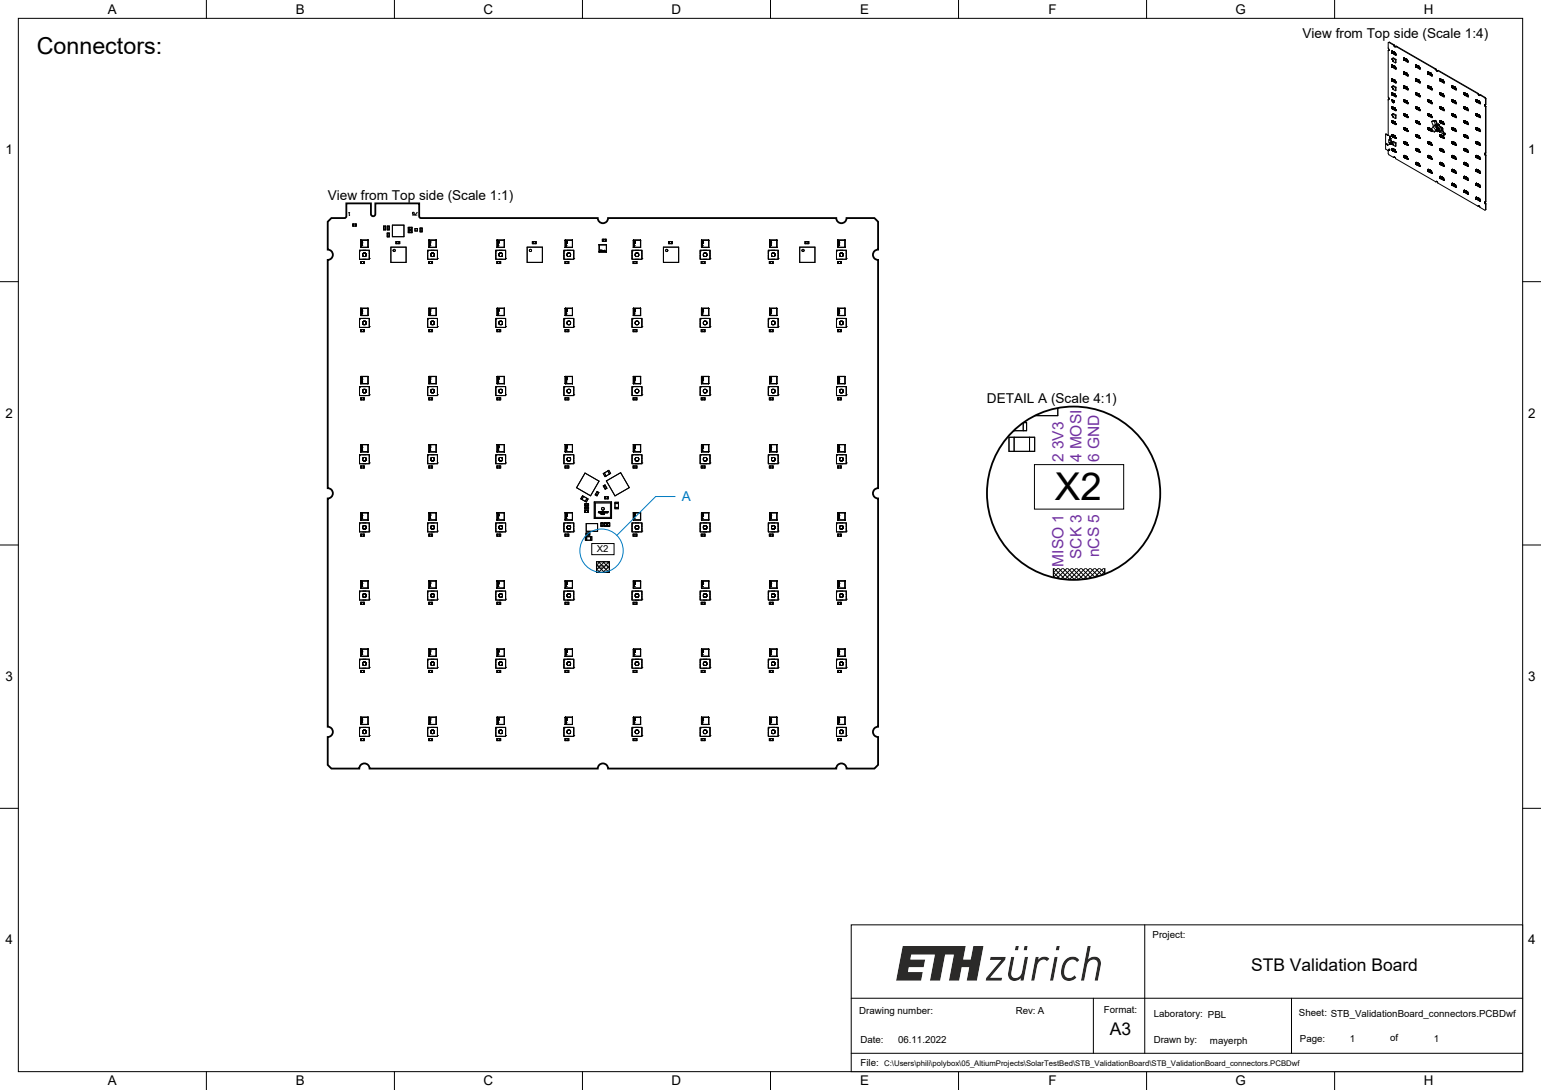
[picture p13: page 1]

View from Top side (Scale 1:4)

View from Top side (Scale 1:1)

DETAIL A (Scale 4:1) MISO 1 SCK 3 nCS 5 2 3V3 4 MOSI 6 GND

File:
C:\Users\phili\polybox\05_AltiumProjects\SolarTestBed\STB_ValidationBoard\STB_ValidationBoard_connectors.PCBDwf

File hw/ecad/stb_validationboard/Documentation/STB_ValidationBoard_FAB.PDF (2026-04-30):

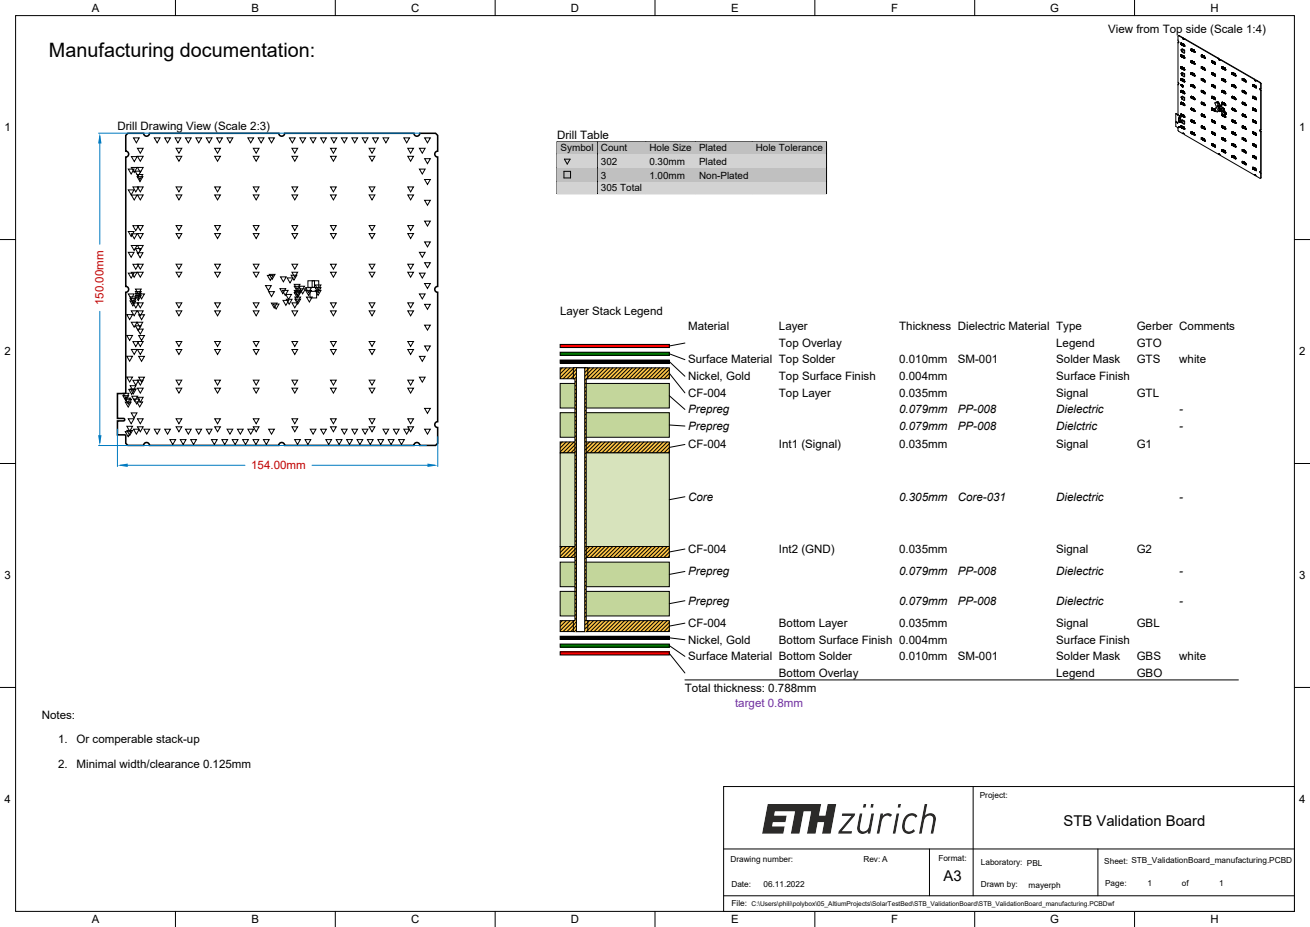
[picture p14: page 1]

View from Top side (Scale 1:4)

Drill Drawing View (Scale 2:3)

1. Or comperable stack-up

File:
C:\Users\phili\polybox\05_AltiumProjects\SolarTestBed\STB_ValidationBoard\STB_ValidationBoard_manufacturing.PCBDwf

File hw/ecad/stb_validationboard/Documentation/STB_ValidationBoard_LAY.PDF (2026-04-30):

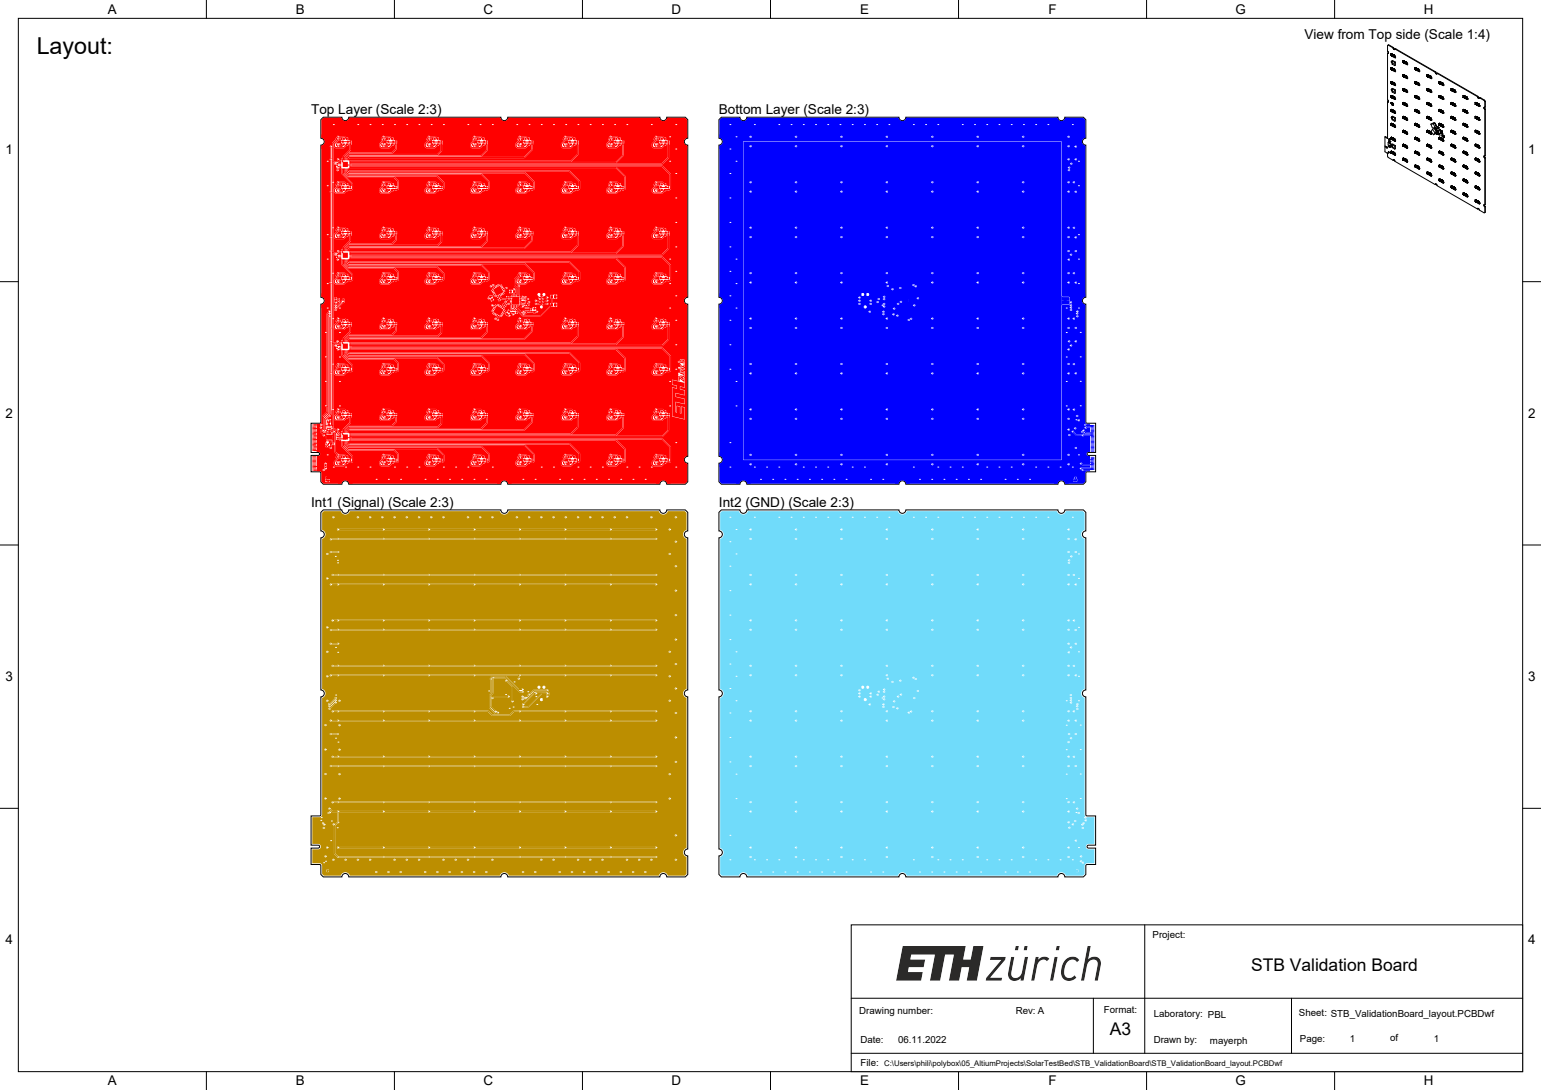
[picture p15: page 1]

View from Top side (Scale 1:4)

File:
C:\Users\phili\polybox\05_AltiumProjects\SolarTestBed\STB_ValidationBoard\STB_ValidationBoard_layout.PCBDwf

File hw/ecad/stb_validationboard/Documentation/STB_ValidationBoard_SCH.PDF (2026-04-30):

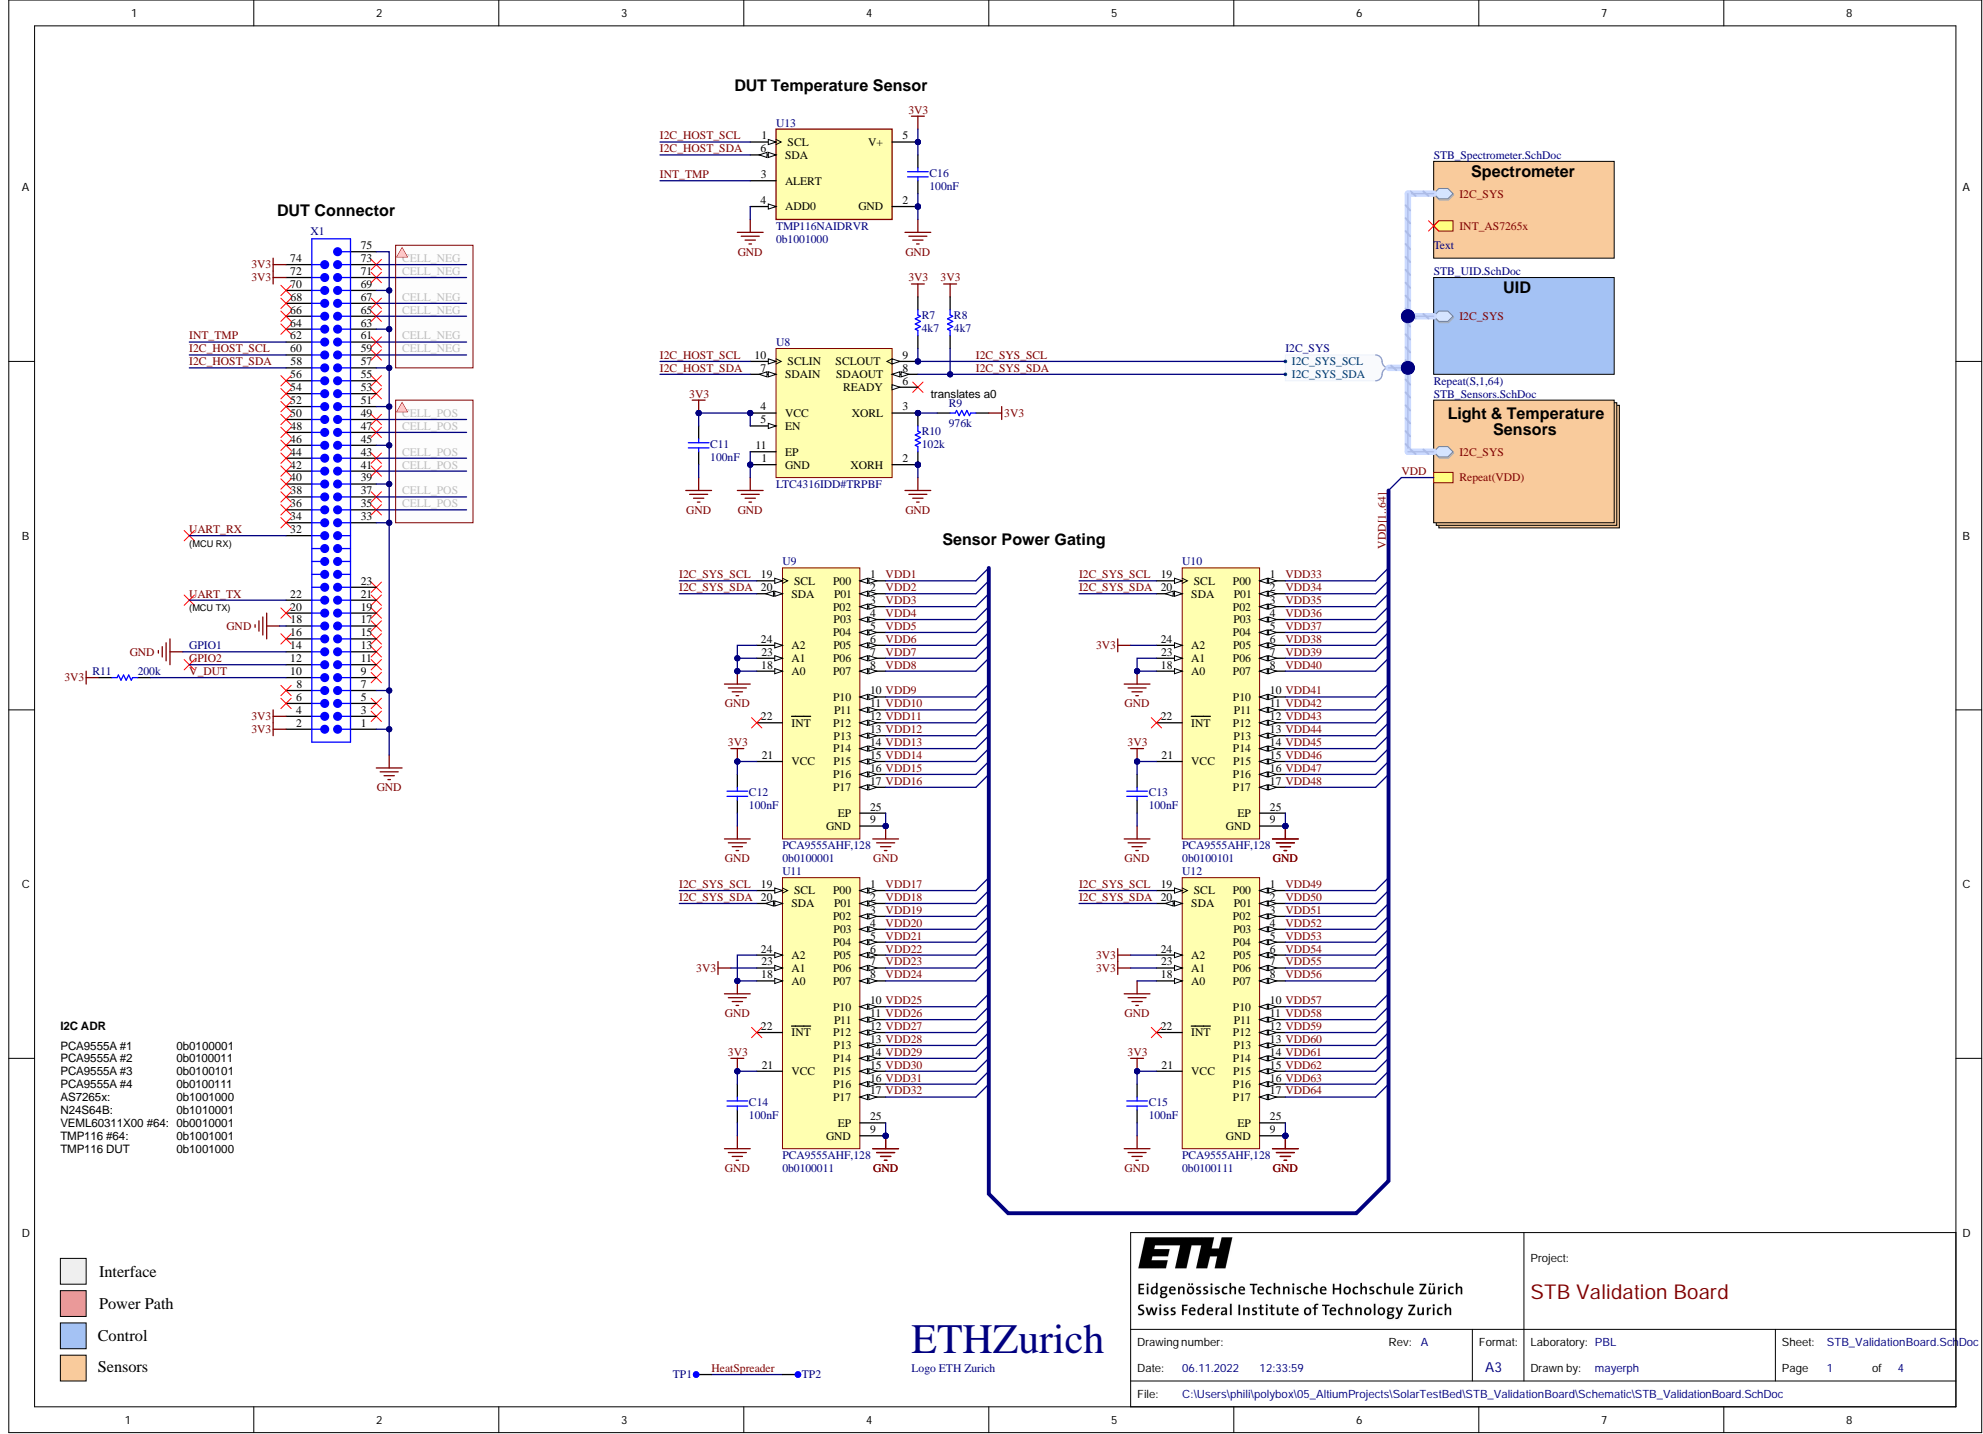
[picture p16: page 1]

Project: STB Valid atio n Bo a rd

Drawin g n umb er: Rev: A Date: 0 6.11.2022 1 2:33:59 | Forma t: A3 | L a b oratory: PBL Drawn by: mayerph | Sh eet: STB_Valid atio nBo ard.SchDoc Page 1 of 4

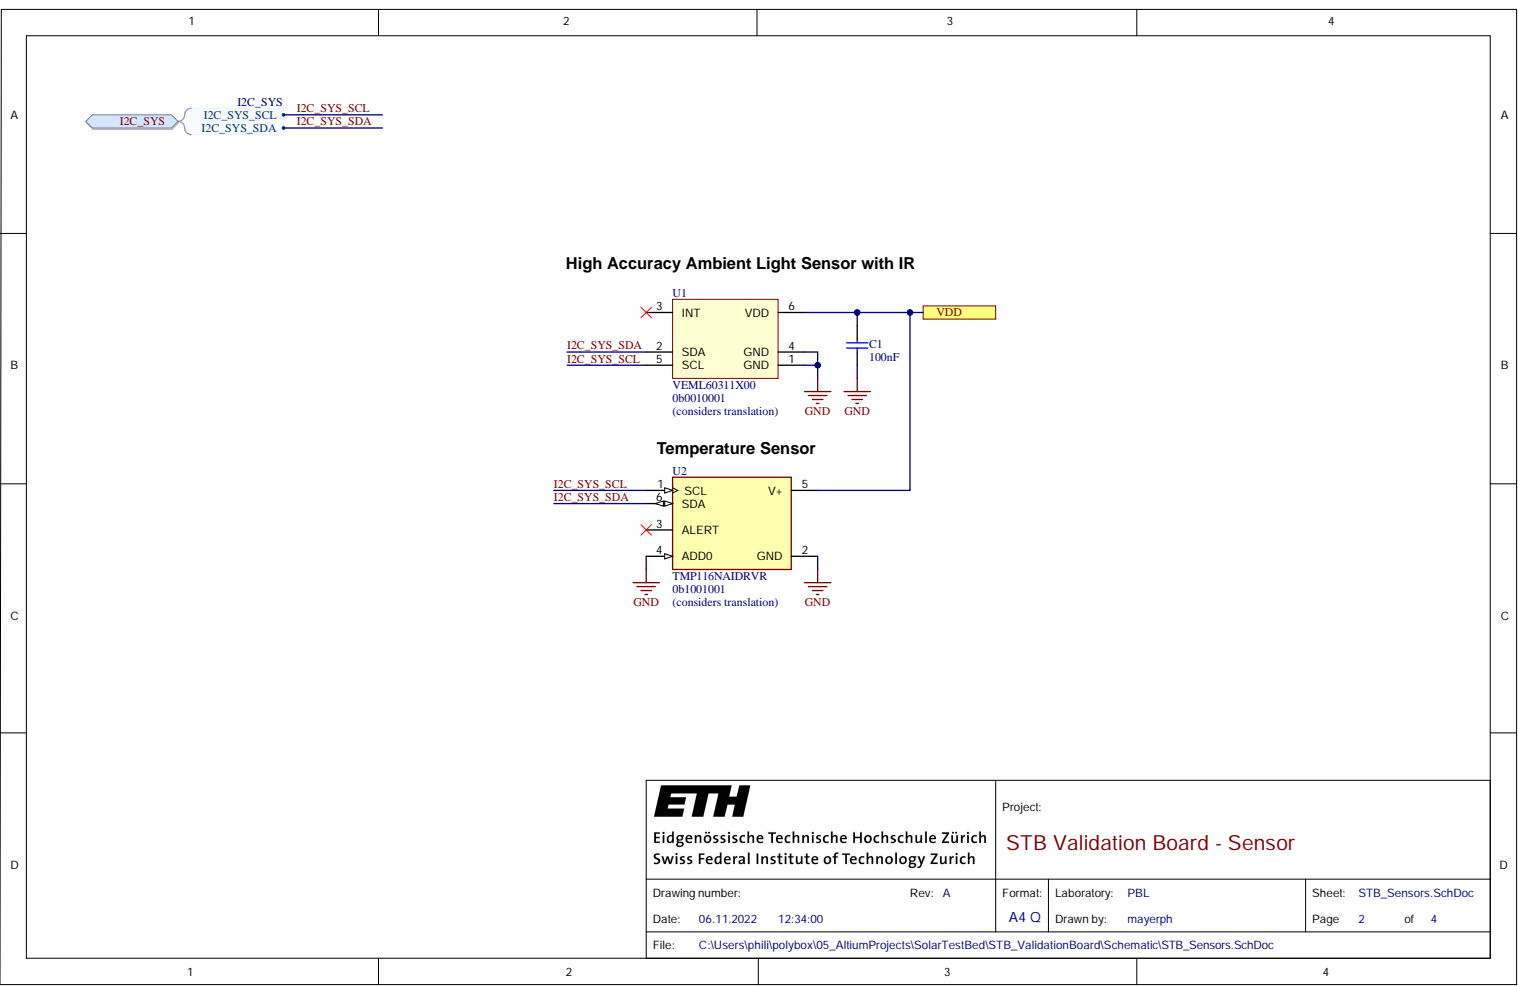
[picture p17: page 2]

High Accuracy Ambient Light Sensor with IR

Project: STB Validation Board - Sensor

Drawing number: Rev: A 12:34:00 | Format: A4 Q | Laboratory: PBL Drawn by: | Sheet: STB_Sensors.SchDoc Page 2 of 4

C:\Users\phili\polybox\05_AltiumProjects\SolarTestBed\STB_ValidationBoard\Schematic\STB_Sensors.SchDoc

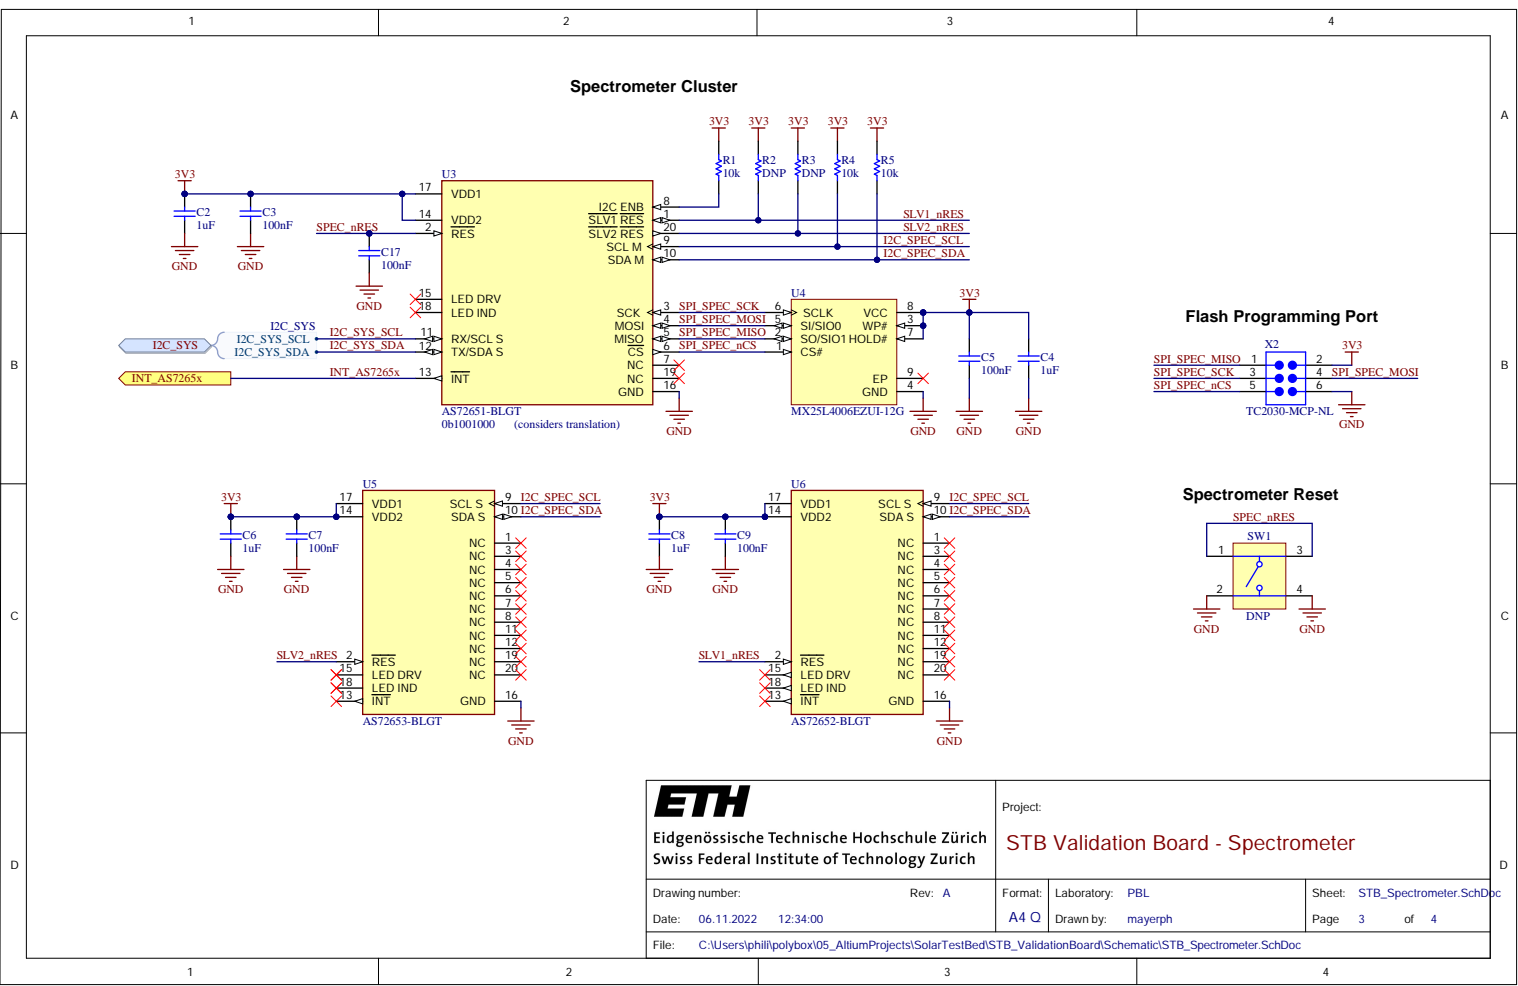
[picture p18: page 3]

Project: STB Validation Board - Spectrometer

Drawing number: Rev: A | Format: | Laboratory: PBL | Sheet: STB_Spectrometer.SchDoc Page 3 of 4

C:\Users\phili\polybox\05_AltiumProjects\SolarTestBed\STB_ValidationBoard\Schematic\STB_Spectrometer.SchDoc

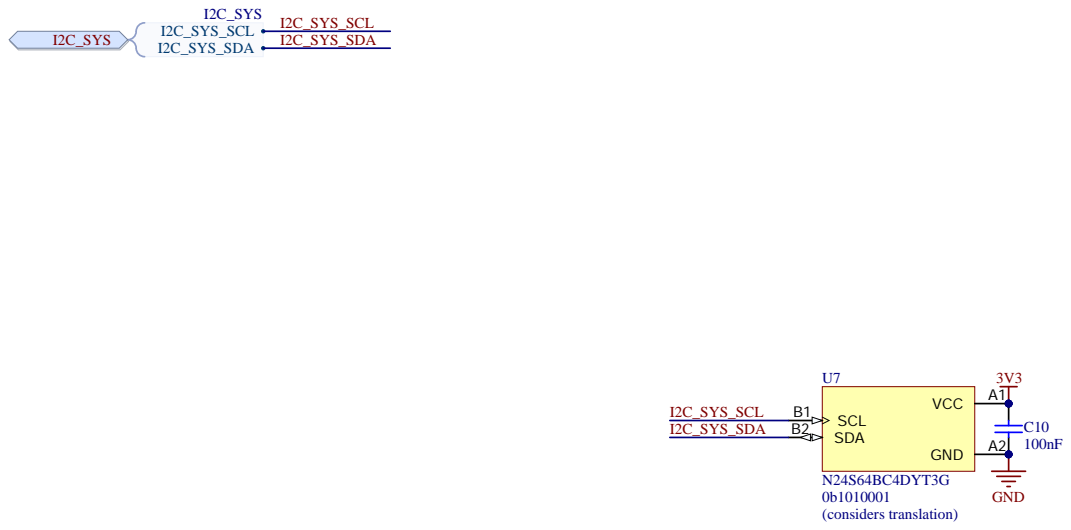
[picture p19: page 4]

Project: STB Validation Board - UID

Drawing number: Rev: A | Format: | Laboratory: PBL | Sheet: STB_UID.SchDoc Page 4 of 4

C:\Users\phili\polybox\05_AltiumProjects\SolarTestBed\STB_ValidationBoard\Schematic\STB_UID.SchDoc

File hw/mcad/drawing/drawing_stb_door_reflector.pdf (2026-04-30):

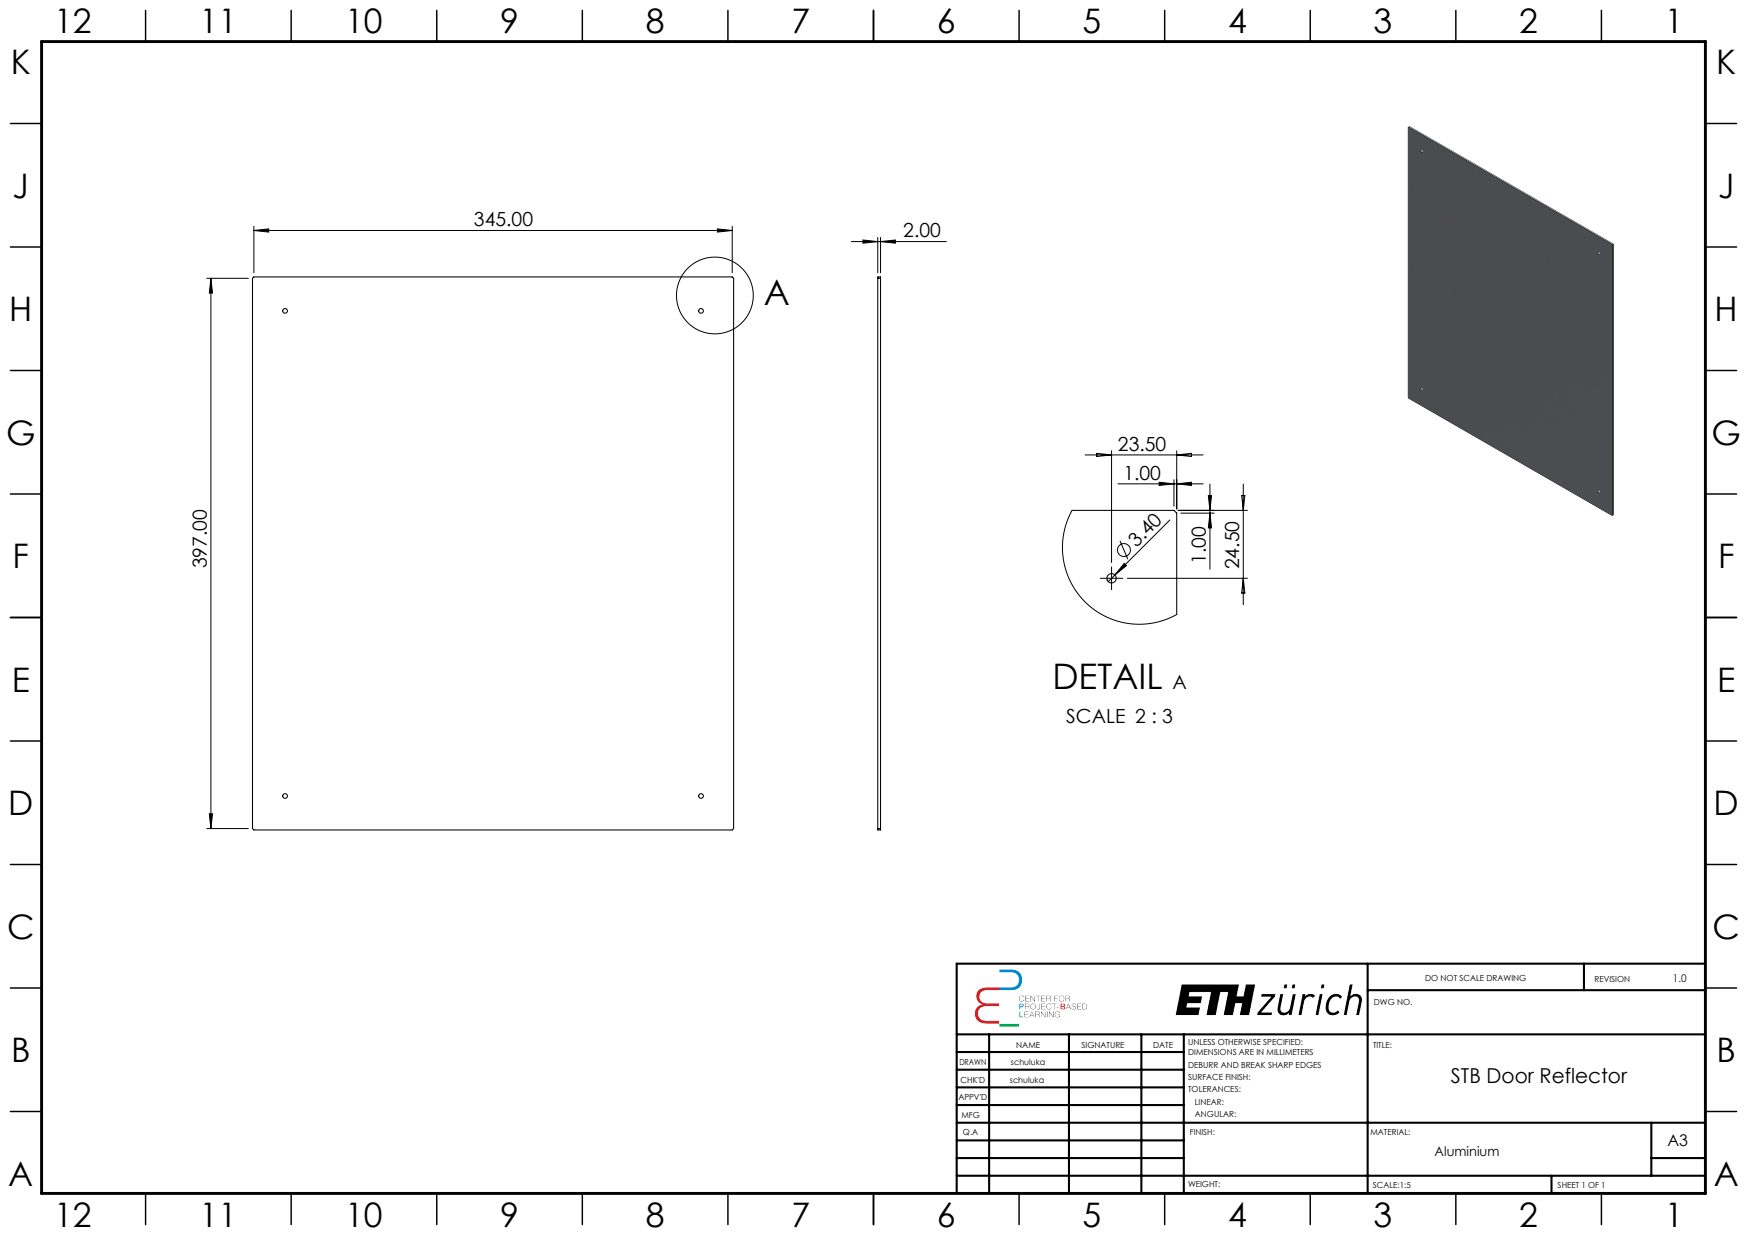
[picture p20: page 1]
DETAIL A; SCALE 2 : 3; DO NOT SCALE DRAWING; REVISION; DWG NO.; SCALE:1:5; SHEET 1 OF 1

NAME | SIGNATURE | DATE | UNLESS OTHERWISE SPECIFIED: DIMENSIONS ARE IN MILLIMETERS DEBURR AND BREAK SHARP EDGES SURFACE FINISH: TOLERANCES: LINEAR: ANGULAR: | TITLE: STB Door Reflector

DRAWN | schuluka
CHK'D | schuluka

APPV'D
MFG
Q.A | | | | FINISH: | MATERIAL: | A3 Aluminium

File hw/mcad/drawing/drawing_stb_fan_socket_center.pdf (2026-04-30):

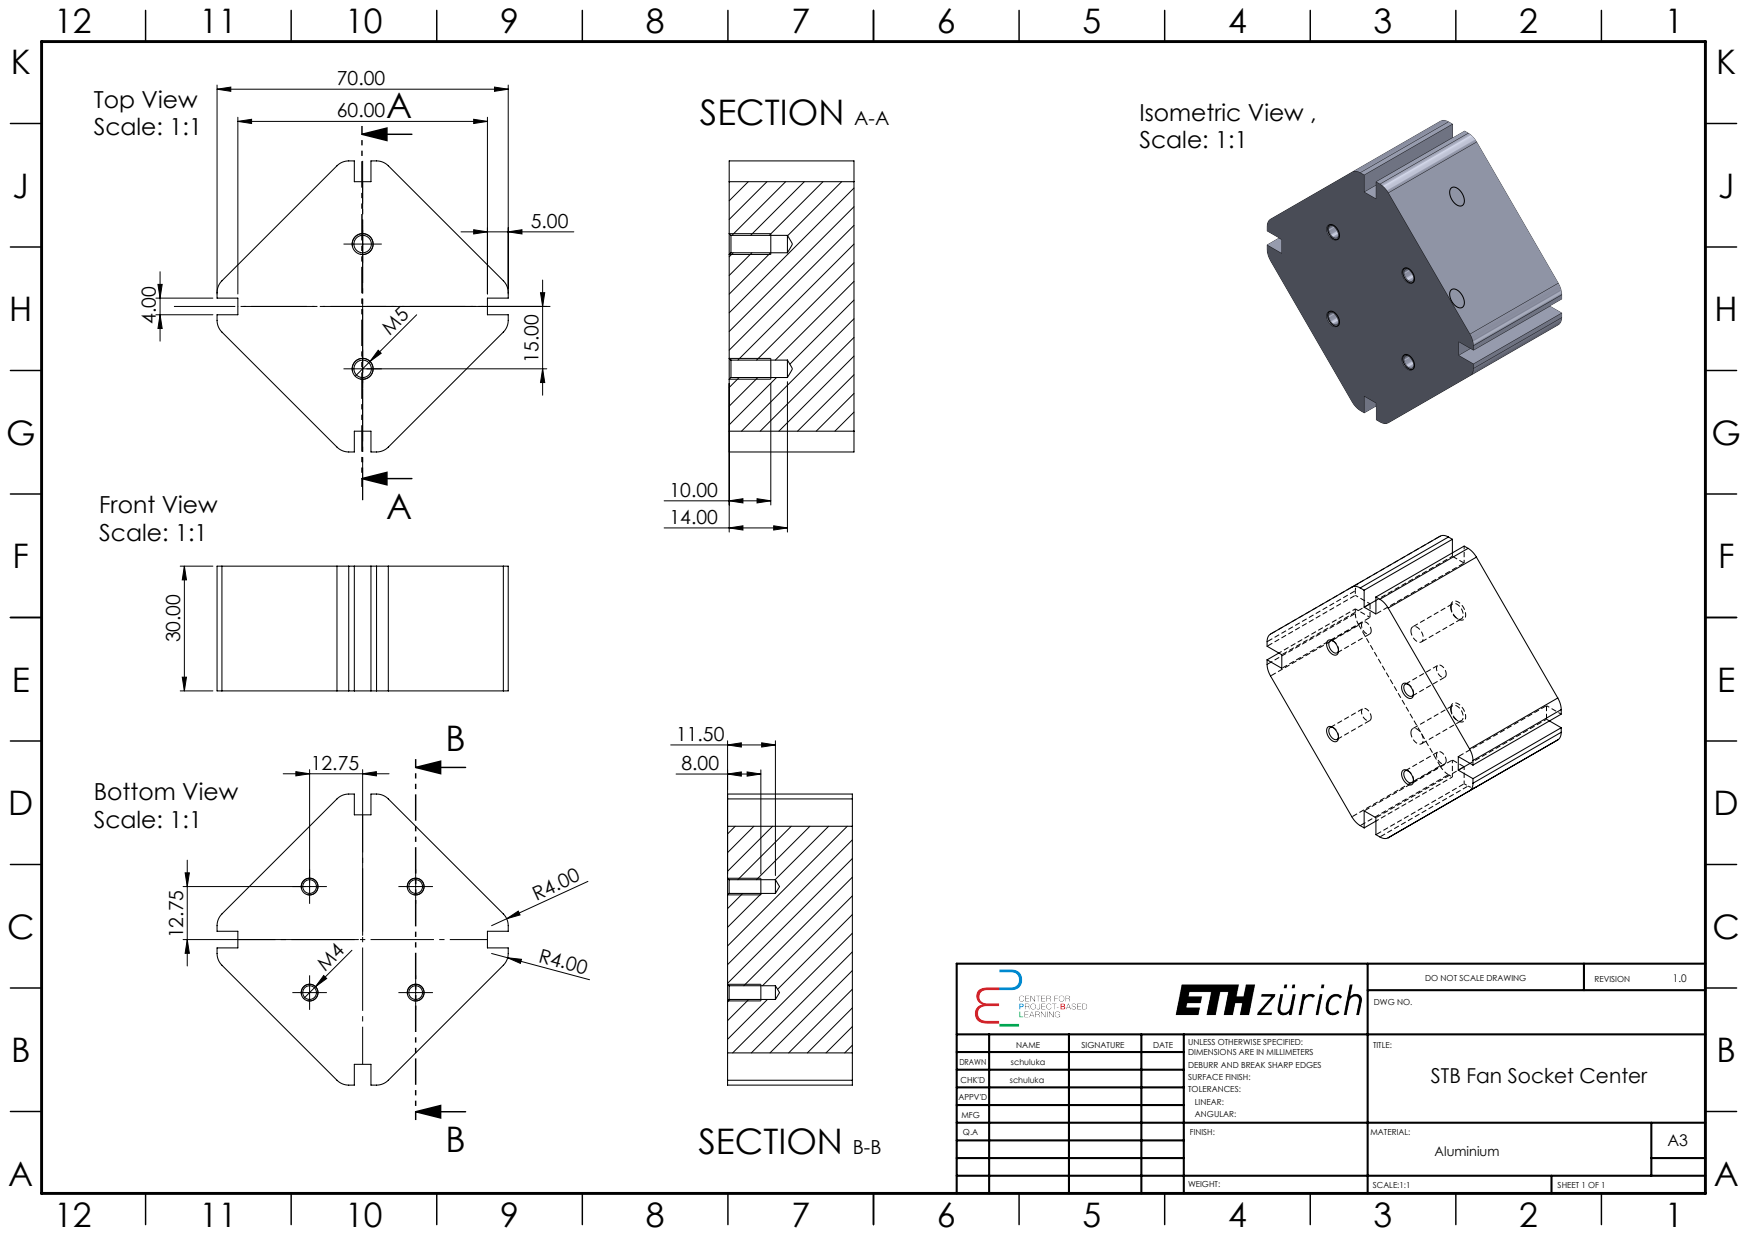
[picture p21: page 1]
SECTION A-A; SECTION B-B; Isometric View , Scale: 1:1; Top View Scale: 1:1; Front View Scale: 1:1; Bottom View Scale: 1:1; DO NOT SCALE DRAWING; REVISION; DWG NO.; SCALE:1:1; SHEET 1 OF 1

NAME | SIGNATURE | DATE | UNLESS OTHERWISE SPECIFIED: DIMENSIONS ARE IN MILLIMETERS DEBURR AND BREAK SHARP EDGES SURFACE FINISH: TOLERANCES: LINEAR: ANGULAR: | TITLE: STB Fan Socket Center

DRAWN | schuluka
CHK'D | schuluka

APPV'D
MFG
Q.A | | | | FINISH: | MATERIAL: | A3 Aluminium

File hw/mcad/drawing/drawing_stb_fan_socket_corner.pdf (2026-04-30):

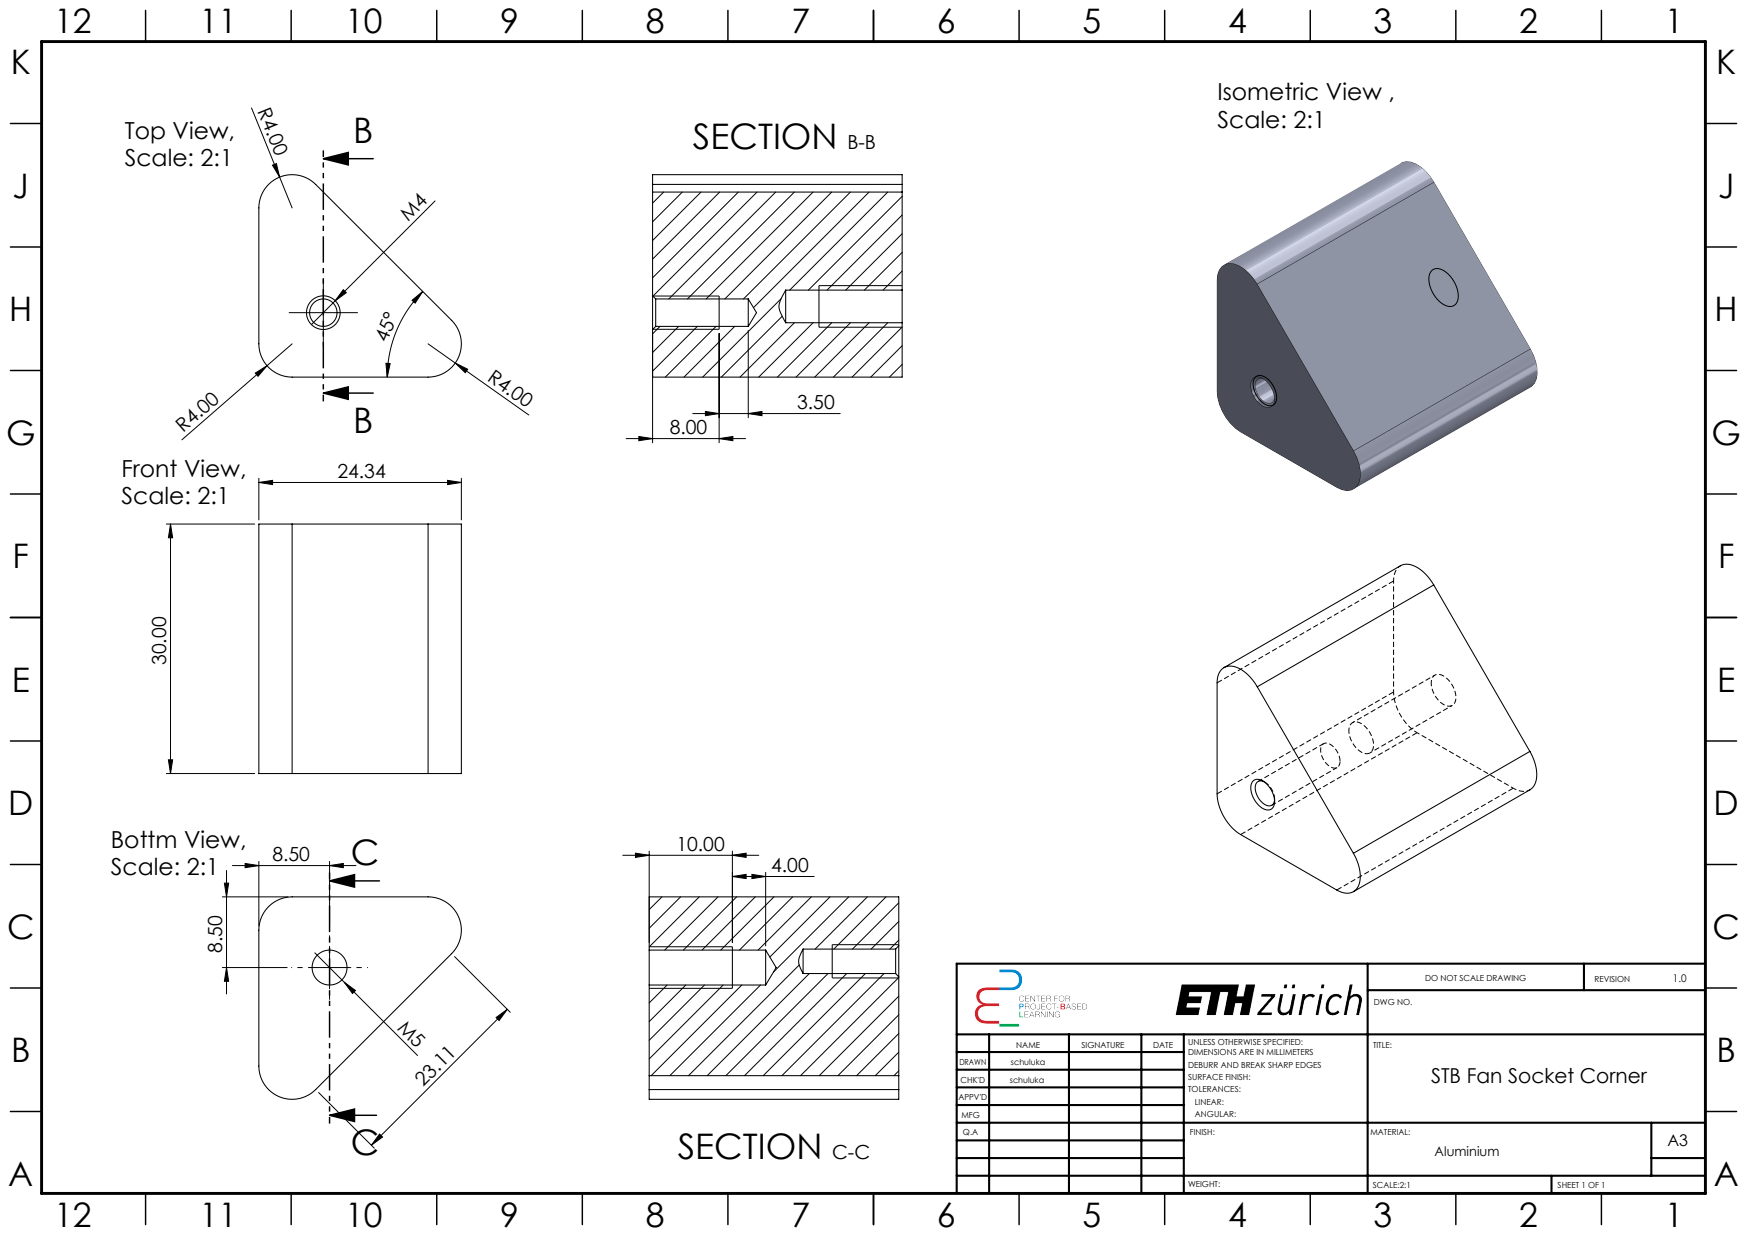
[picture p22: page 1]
SECTION B-B; SECTION C-C; Top View, Scale: 2:1; Front View, Scale: 2:1; Bottm View, Scale: 2:1; Isometric View , Scale: 2:1; DO NOT SCALE DRAWING; REVISION; DWG NO.; SCALE:2:1; SHEET 1 OF 1

NAME | SIGNATURE | DATE | UNLESS OTHERWISE SPECIFIED: DIMENSIONS ARE IN MILLIMETERS DEBURR AND BREAK SHARP EDGES SURFACE FINISH: TOLERANCES: LINEAR: ANGULAR: | TITLE: STB Fan Socket Corner

DRAWN | schuluka
CHK'D | schuluka

APPV'D
MFG
Q.A | | | | FINISH: | MATERIAL: | A3 Aluminium

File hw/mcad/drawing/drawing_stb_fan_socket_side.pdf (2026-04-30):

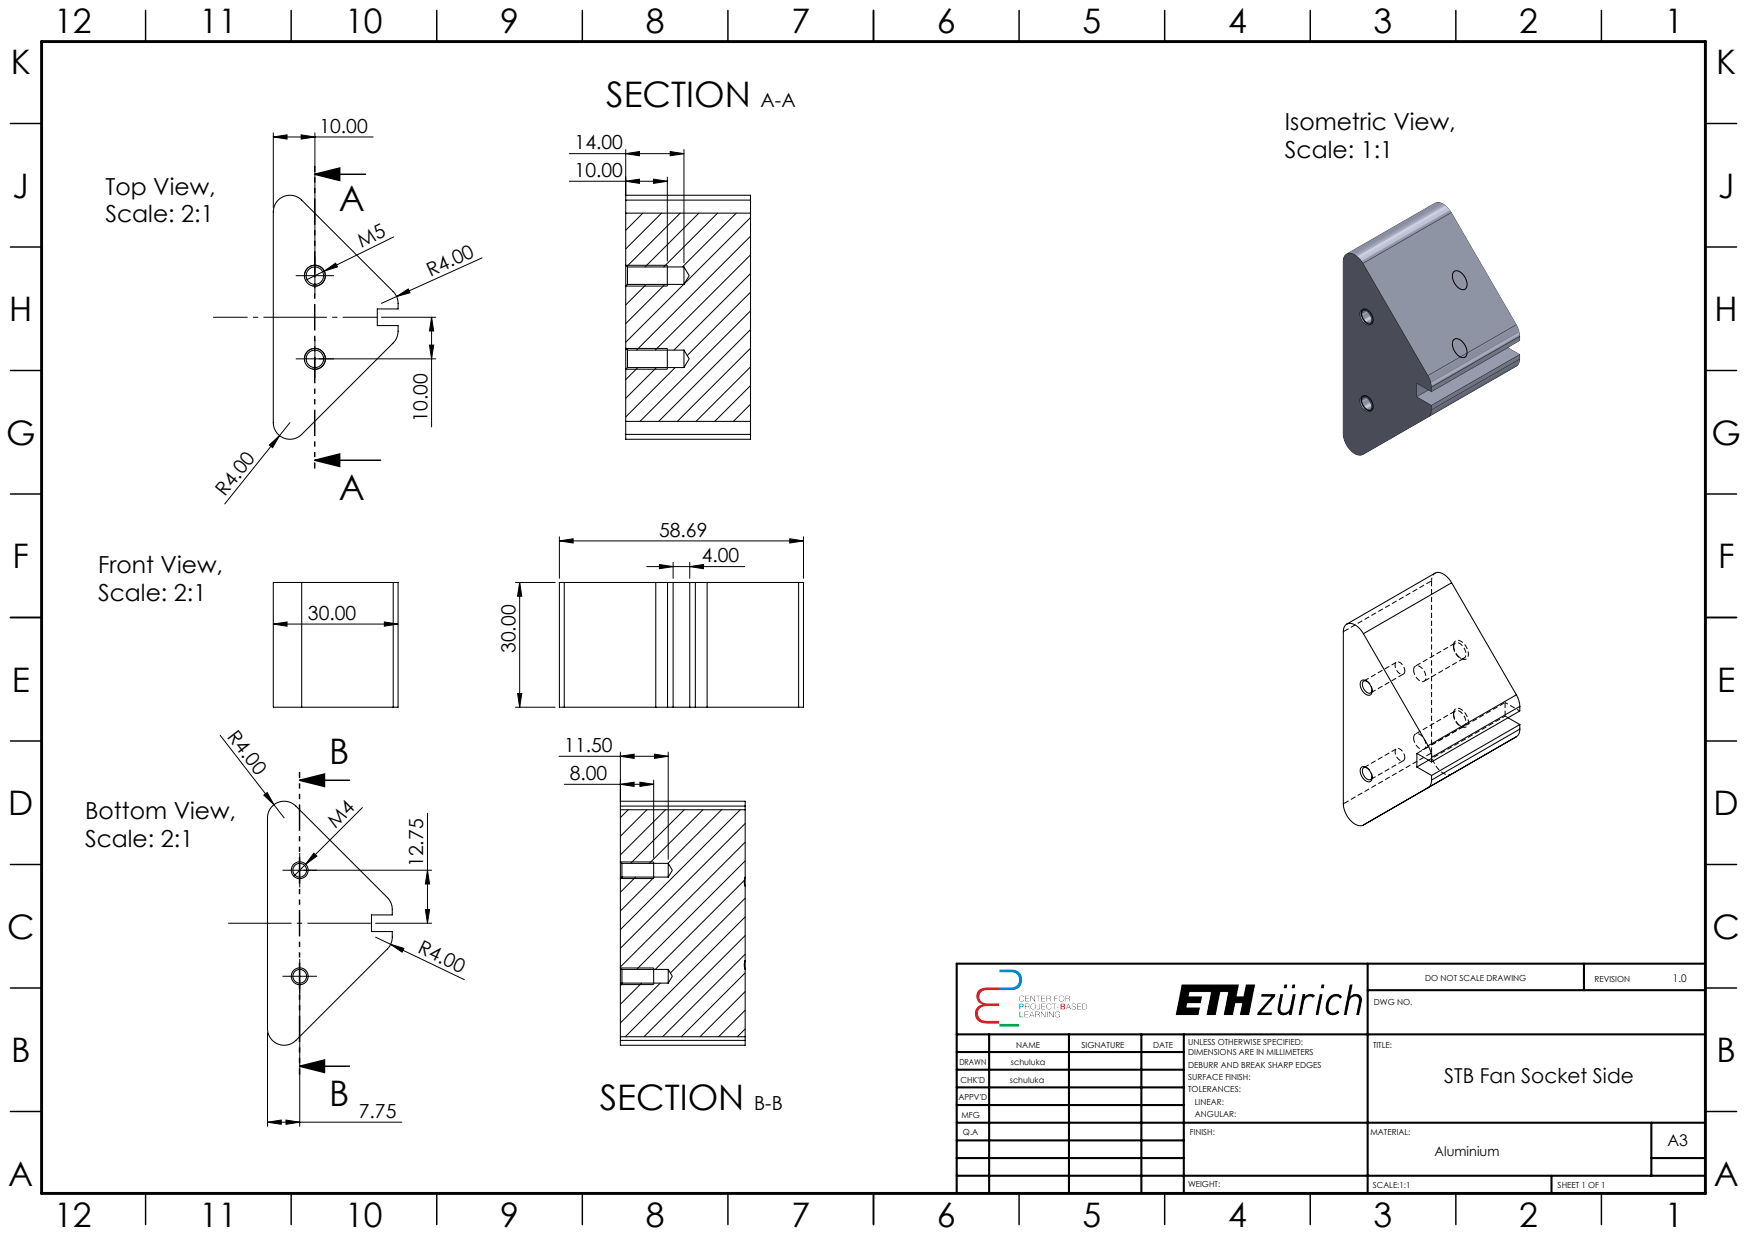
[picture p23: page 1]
SECTION A-A; SECTION B-B; Bottom View, Scale: 2:1; Front View, Scale: 2:1; Top View, Scale: 2:1; Isometric View, Scale: 1:1; DO NOT SCALE DRAWING; REVISION; DWG NO.; SCALE:1:1; SHEET 1 OF 1; schuluka; STB Fan Socket Side

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

APPV'D
MFG
Q.A | FINISH: | MATERIAL: | A3 Aluminium

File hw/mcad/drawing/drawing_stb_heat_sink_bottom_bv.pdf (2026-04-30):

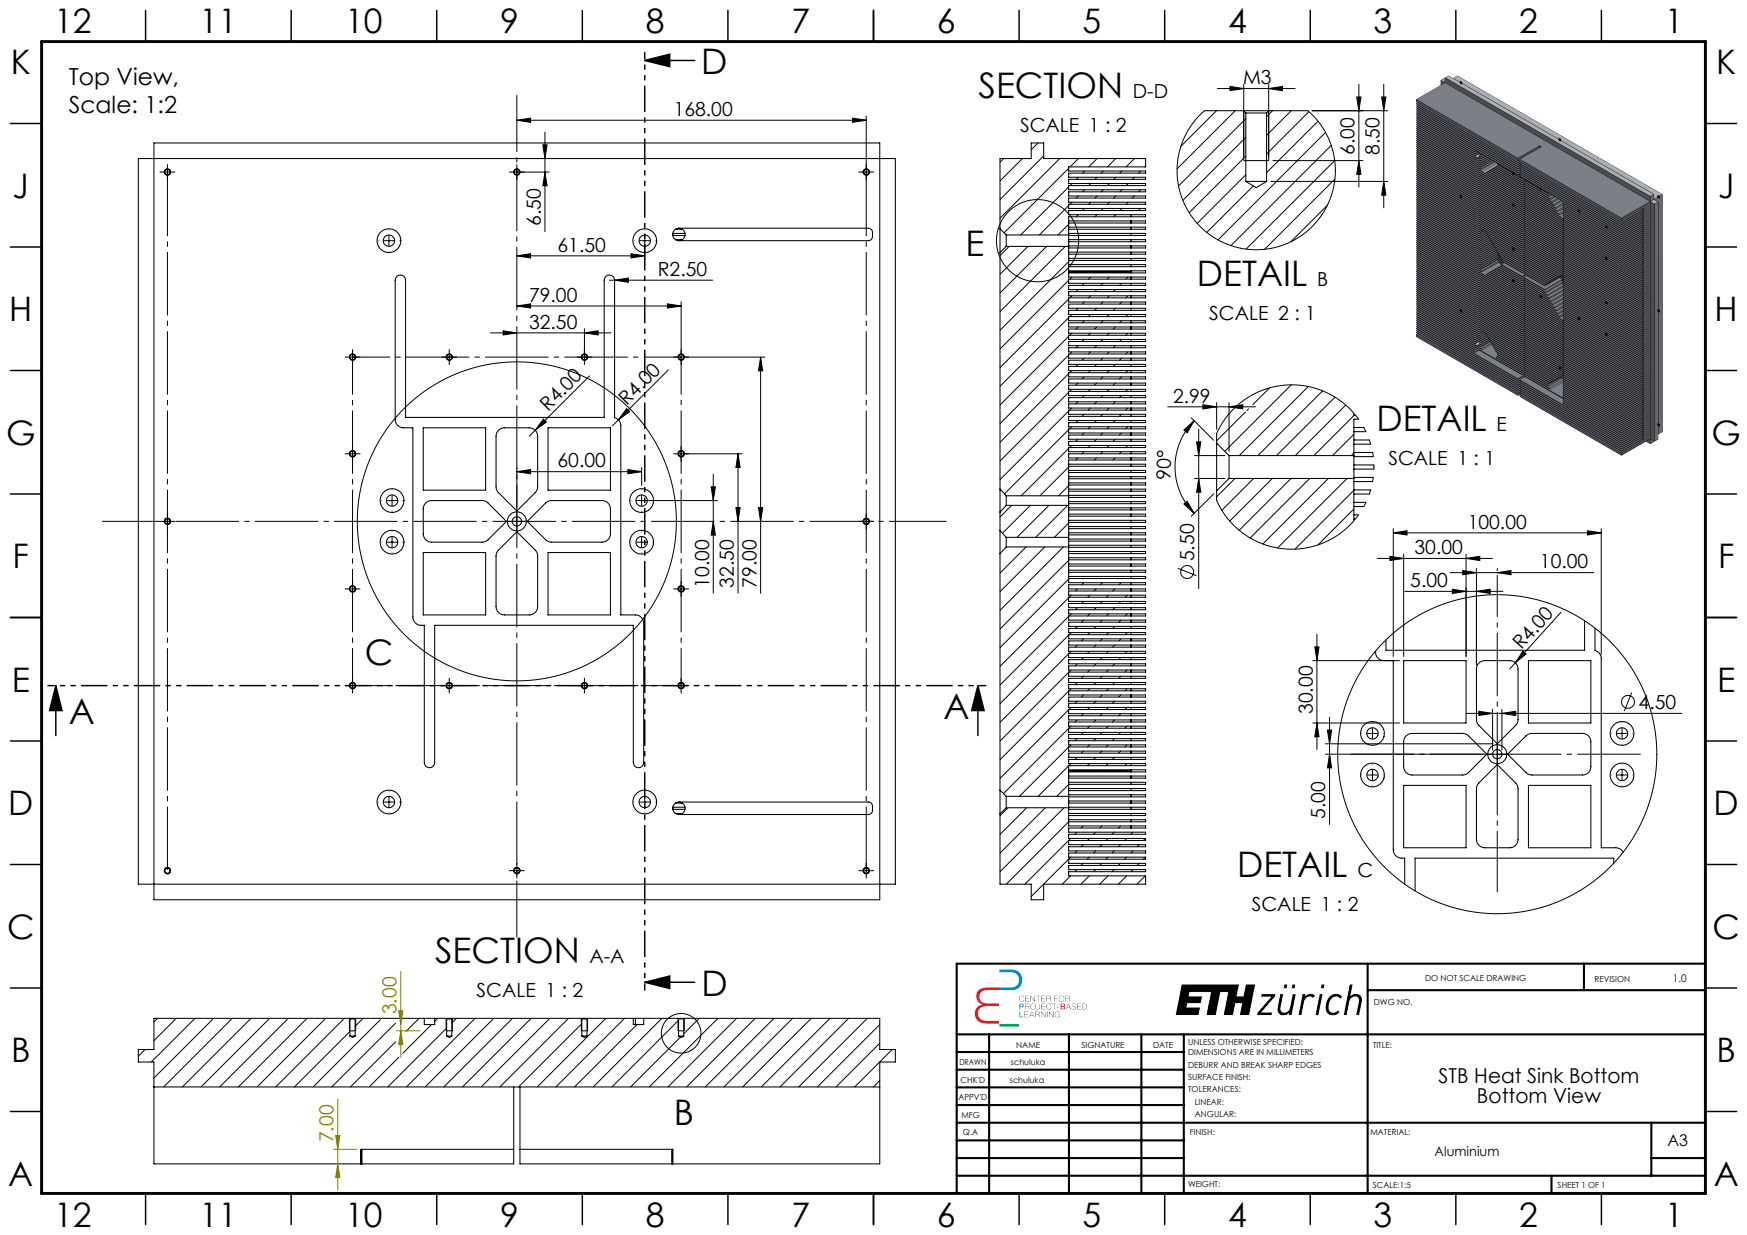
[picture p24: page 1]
SECTION A-A; SCALE 1 : 2; SCALE 2 : 1; SECTION D-D; SCALE 1 : 1; Top View, Scale: 1:2; DO NOT SCALE DRAWING; REVISION; DWG NO.; SCALE:1:5; SHEET 1 OF 1

NAME | SIGNATURE | DATE | UNLESS OTHERWISE SPECIFIED: DIMENSIONS ARE IN MILLIMETERS DEBURR AND BREAK SHARP EDGES SURFACE FINISH: TOLERANCES: LINEAR: ANGULAR: | TITLE: STB Heat Sink Bottom Bottom View

DRAWN | schuluka
CHK'D | schuluka

APPV'D
MFG
Q.A | | | | FINISH: | MATERIAL: | A3 Aluminium

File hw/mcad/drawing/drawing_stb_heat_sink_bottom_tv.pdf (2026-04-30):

DETAIL A; SCALE 2 : 1; SECTION B-B; SCALE 1 : 2; Top View, Scale: 1:2; DO NOT SCALE DRAWING; REVISION; DWG NO.; SCALE:1:5; SHEET 1 OF 1

NAME | SIGNATURE | DATE | UNLESS OTHERWISE SPECIFIED: DIMENSIONS ARE IN MILLIMETERS DEBURR AND BREAK SHARP EDGES SURFACE FINISH: TOLERANCES: LINEAR: ANGULAR: | TITLE: STM Heat Sink Bottom Top View

DRAWN | schuluka
CHK'D | schuluka

APPV'D
MFG
Q.A | | | | FINISH: | MATERIAL: | A3 Aluminium

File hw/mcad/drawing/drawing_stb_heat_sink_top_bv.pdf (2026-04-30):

SECTION D-D; SCALE 1 : 2; SECTION E-E; SCALE 1 : 1; SCALE 2 : 1; Top View, Scale: 1:2; DO NOT SCALE DRAWING; REVISION; DWG NO.; SCALE:1:5; SHEET 1 OF 1

86.00
168.00
135.00

NAME | SIGNATURE | DATE | UNLESS OTHERWISE SPECIFIED: DIMENSIONS ARE IN MILLIMETERS DEBURR AND BREAK SHARP EDGES SURFACE FINISH: TOLERANCES: LINEAR: ANGULAR: | TITLE: STB Heat Sink Top Bottom View

DRAWN | schuluka
CHK'D | schuluka

APPV'D
MFG
Q.A | | | | FINISH: | MATERIAL: | A3 Aluminium
